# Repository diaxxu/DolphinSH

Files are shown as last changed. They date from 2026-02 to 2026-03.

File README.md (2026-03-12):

# VTOL FPV Fixed-Wing UAV Project

<p align="center">
 
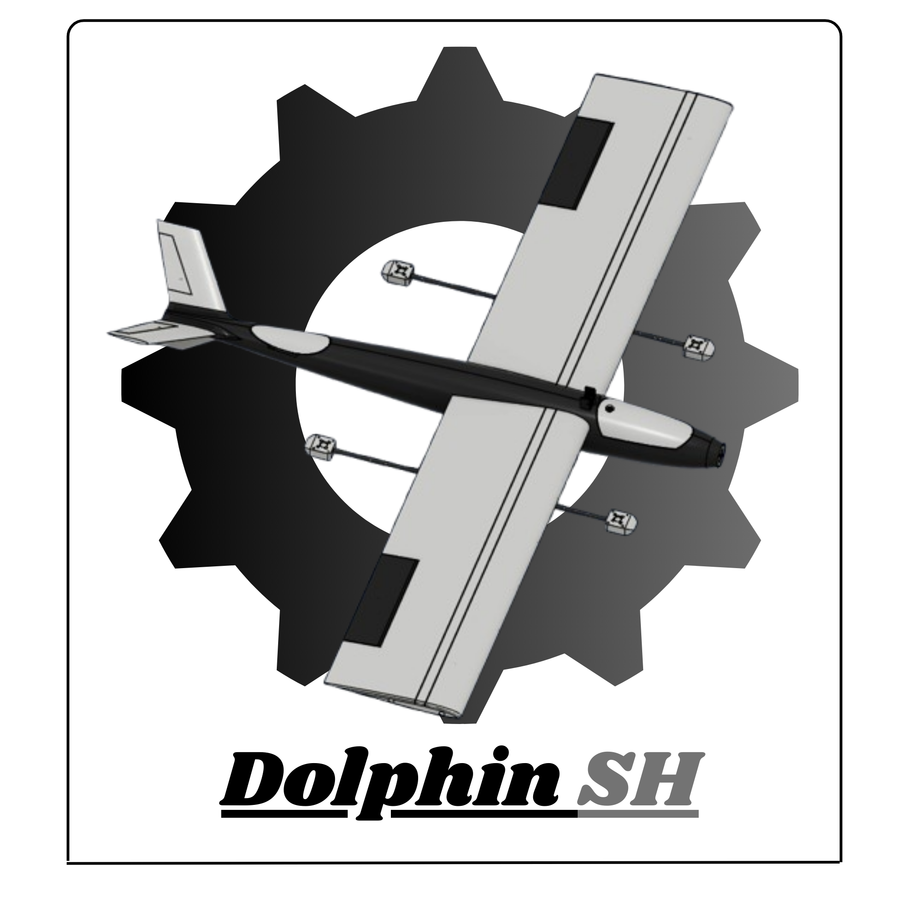
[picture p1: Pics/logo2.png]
Plane Front
   
</p>

### discord server : https://discord.gg/rtFu4ADm9m

## Overview

This project is a 3d printed VTOL (Vertical Take-Off and Landing) fixed-wing UAV with FPV (First Person View)  
It combines quad lift motors for vertical flight ( kinda like a drone ) but with a additional forward propulsion motor for efficient cruise.
I built this project to learn how to properly design, build a UAV (Unmanned Aerial Aircraft)

---

## Plane Features

- High-wing configuration
- 3d printed fuselage and wings (97% of the plane is 3d printed)  
- Quad vertical lift motors for VTOL capability  
- Nose-mounted motor for cruise propulsion  
- V tail configuration  
- Back fin designed for stability in forward flight at moderate speed
- easy access for mounting servo in the fuselage thanks to a BWD CAN and a FWD canopy

---

## Design Objectives
i made it to be or have : 
- Stable hover and smooth transition to forward flight  
- High structural stiffness with minimal weight  
- Efficient cruise performance  
- Predictable aerodynamic behavior at low Reynolds numbers  
- Modular fuselage for maintenance and upgrades  

---

## Technical Specifications 

- Wingspan: 1300 mm

- Wing Area: 0.286 m²

- Aspect Ratio: 5.9

- Wing Loading: 7.0 kg/m² (≈ 68.5 N/m²)

- Estimated Stall Speed: ~35 km/h (≈ 9.7 m/s)

- Cruise Speed (est.): ~72 km/h (20 m/s)

- Cruise Lift Coefficient (CL @ 20 m/s): ~0.28

- Reynolds Number (@ cruise): ~300,000

- Airfoil: Semi-Symmetrical (Cambered SS)

- Estimated Weight: 2046 g (~20 N)

- Fuselage Length: 888 mm

- Max Fuselage Diameter: 273 mm

## Propulsion

- Lift Motors: 4 × A2212 1000KV

- Max Thrust (VTOL total): ~3.2 kg

- VTOL Thrust-to-Weight Ratio: ~1.6

- Hover Endurance (est.): 4-6 minutes

- Cruise Motor: 1 × A2212 1000KV

- Cruise Power Consumption (est.): ~100 W

- Estimated Cruise Endurance: ~14–15 minutes

## Power System

- Battery: 3S 2200mAh 30C (~24 Wh usable energy)

- ESC: 30A (all motors)

## Avionics

- Flight Controller: DakeFPV F722 X6 (any F7 class FC compatible)
- GPS : HGRLC M-100
- ESC : generic 30amp
- FPV : generic one off aliexpress

---

## Firmware

the Firmware thats going to run is Inav its a lightweight program that is capable of autonomously flying the UAV to pre-programmed waypoint or loiter ( always wanted to do this imagine letting go of the transmitter and the plane continue to fly itself thats literally magic ) 

---

## Firmware Flashing Instructions

### 1. Install Required Software
1. Download and install **INAV Configurator** from the official GitHub release page.
2. Install the appropriate USB drivers for your flight controller (CP210x, STM32 VCP, or DFU drivers depending on the board).

### 2. Connect the Flight Controller
3. Connect the flight controller (FC) to your PC using a USB-C cable.
4. Wait for the operating system to recognize the device.
5. Confirm that a new COM port appears in your device manager.

### 3. Enter Bootloader Mode
6. If required, hold the **BOOT** button on the FC while plugging in the USB cable.
7. Alternatively, use the “Reboot to Bootloader” option inside INAV Configurator (if firmware is already present).

### 4. Flash Firmware
8. Open **INAV Configurator**.
9. Go to the **Firmware Flasher** tab.
10. Select the correct target for your flight controller (verify the exact board name printed on the FC).
11. Select the desired firmware version (use the latest stable release unless specific testing is required).
12. Enable **Full chip erase** (recommended for clean installations).
13. Click **Load Firmware Online**.
14. Click **Flash Firmware**.
15. Wait until flashing is complete. Do not disconnect power during this process.

### 5. Initial Setup
16. After flashing, reconnect to the FC.
17. Apply default settings.
18. Configure board alignment if necessary.
19. Calibrate the accelerometer.
20. Set up ports (UART configuration for receiver, GPS, etc.).
21. Configure receiver protocol.
22. Configure motor outputs and mixer type (VTOL / fixed wing as required).
23. Set failsafe parameters.
24. Save and reboot.

### 6. Verification
25. Confirm sensor functionality (gyro, accelerometer, barometer, GPS if installed).
26. Verify receiver inputs respond correctly.
27. Check motor output order and direction (remove propellers before testing).
28. Perform a final configuration backup.

attention! Firmware flashing and configuration must always be done without propellers installed to prevent accidental motor startup.

---

## Schematic ( wire diagram 
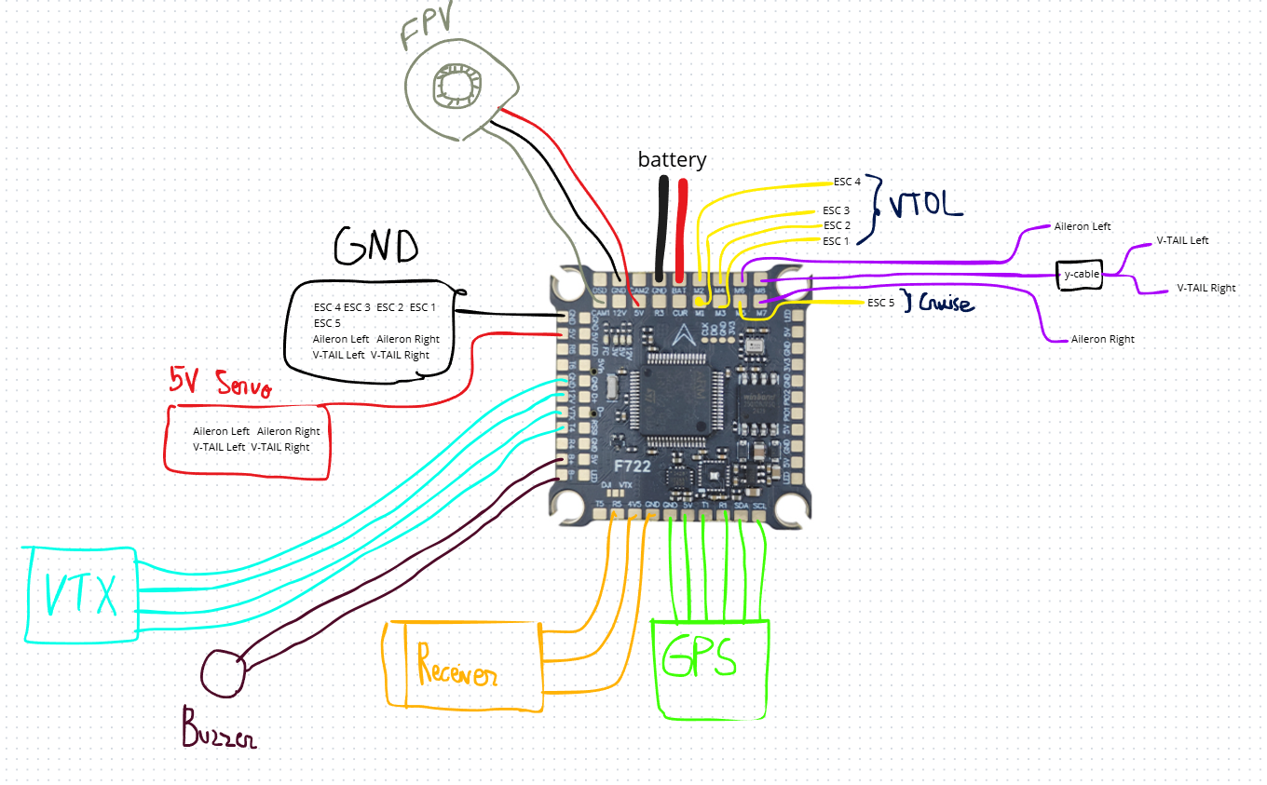
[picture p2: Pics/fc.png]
fc

-
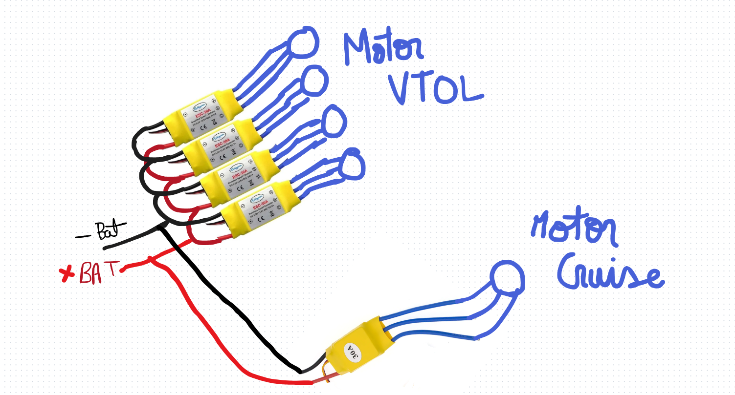
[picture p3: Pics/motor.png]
motor

-
---
## FAQ

**Q: Can this plane really hover like a drone?**  
A: Yes, the quad lift motors provide vertical takeoff and stable hover.

**Q: How difficult is the hover-to-cruise transition?**  
A: It’s one of the trickiest parts. Proper PID tuning in iNav and smooth throttle control are key to avoiding instability.

**Q: Can I use a different flight controller?**  
A: Yes, any controller that supports VTOL and iNav or Ardupilot firmware should work (and have 8 signal pins), though wiring and mounting may need adjustments. 

**Q: How long does it take to assemble?**  
A: Printing and assembly can take several days (or weeks!), depending on your 3D printing setup and experience. 

**Q: Is it possible to carry a camera payload?**  
A: Small FPV cameras work fine. =)

**Q: Can I scale the design larger or smaller?**  
A: Yes, but aerodynamics and weight distribution change with scale. Lift motors may need different thrust ratings.

**Q: How do you troubleshoot vibrations from the motor arms?**  
A: good carbon fiber tube is enough check for any error in the manufacturing side

**Q: How safe is the plane for beginners?**  
A: It’s moderately advanced. Beginners should test hover flights in a wide, open area and start with short, low-altitude hops.

**Q: What kind of maintenance is required?**  
A: Regularly check motor screws, propeller condition, and servo linkages. easy access panels in the fuselage makes replacing parts faster.

**Q: Can the firmware do autonomous flight?**  
A: Yes, iNav can handle waypoint navigation and loitering, letting the plane fly itself once configured correctly.

---

## COOL Pics

Plane VIS
-
PALEN
-
PALEN
-
PALEN

-
PALEN
-
Render
Plane Front
---

## Engineering Challenges

- Drag from exposed lift motors during cruise  
- Structural vibration and resonance of motor arms  ( simulation ) 
- Stable hover-to-cruise transition ( hard ) 
- Accurate CG placement ( moderate ) 

---

## BoM ( secret sauce!!) 
 
| Component | Specification | Quantity | Price  | Link |
| --- | --- | --- | --- | --- |
| Set of motor, ESC, and propellers | A2212 1000KV / 30A ESC / 23cm props | 4 | $64.01 | [AliExpress](https://a.aliexpress.com/_EJaQqYY) |
| FPV | Camera with VTX and goggle | 1 | $86.94 | [AliExpress](https://a.aliexpress.com/_EuSo3te) |
| Telemetry | LoRa LR02 ASR6601 (10 km range) | 1 | $25.63 | [AliExpress](https://a.aliexpress.com/_EJNQwhK) |
| Servo | SG90 (360°) | 5 | $8.78  | [AliExpress](https://a.aliexpress.com/_EHJRpG8) |
| Carbon Fiber Tube | 9x7x500 mm | 4 | $14.55 | [AliExpress](https://a.aliexpress.com/_EH2rwjI) |
| Servo Rods | 19 cm, 1.2 mm | 20 | $4.85  | [AliExpress](https://a.aliexpress.com/_EJKOflA) |
| Copper Wire (signal & FC) | 10 m, 26 AWG, yellow | 1 | $3.97  | [AliExpress](https://a.aliexpress.com/_EzUnszi) |
| Copper Wire (batteries) | 10 m, 16 AWG, black | 1 | $13.83 | [AliExpress](https://a.aliexpress.com/_EztPdHO) |
| Magnet | 3mmx1mm | 50 | $6.94  | [AliExpress](https://a.aliexpress.com/_EJExample)  |
| Square tube carbon fiber | 10x10x8.5mm 500mm | 2 | $16.7  | [AliExpress](https://a.aliexpress.com/_EJExample2) |
| Dupont line (connectors) | 10cm 3 kind | 120 | $5.07  | [AliExpress](https://a.aliexpress.com/_EJExample3) |
|Printing legion | shipping from india to morocco | 1 | $25 |  

i already own 1 flightcontroller , 1 motor , 1 esc , 1 battery, 1 gps , 1 receiver and transmitter 

### the TOTAL : 291.11$

## Credits

A big thanks to Hack Club and Blueprint for making this possible without them, all these project would been just a .step file <p/> 
also i want to thank the Reviewers who are doing an incredible job, kudos !

---
## Disclaimer
<p align="center">
 Plane Front
</p>
This project is experimental and intended for research and educational purposes.  
All flight testing must be conducted in safe and controlled environments.

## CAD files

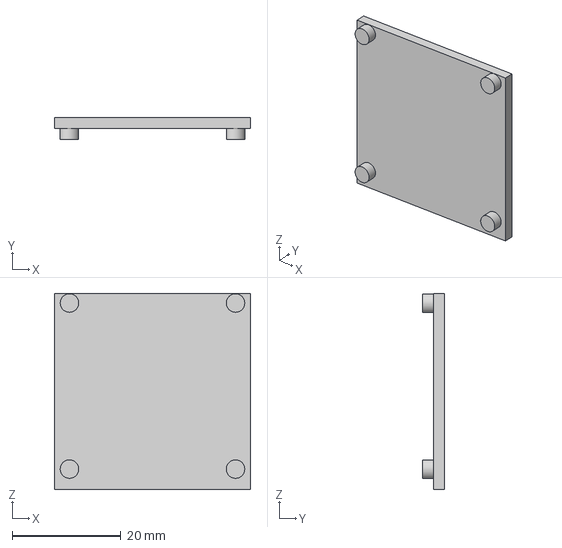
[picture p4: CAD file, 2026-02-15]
CAD/flight controller.step
36.0 x 4.00 x 36.0 mm

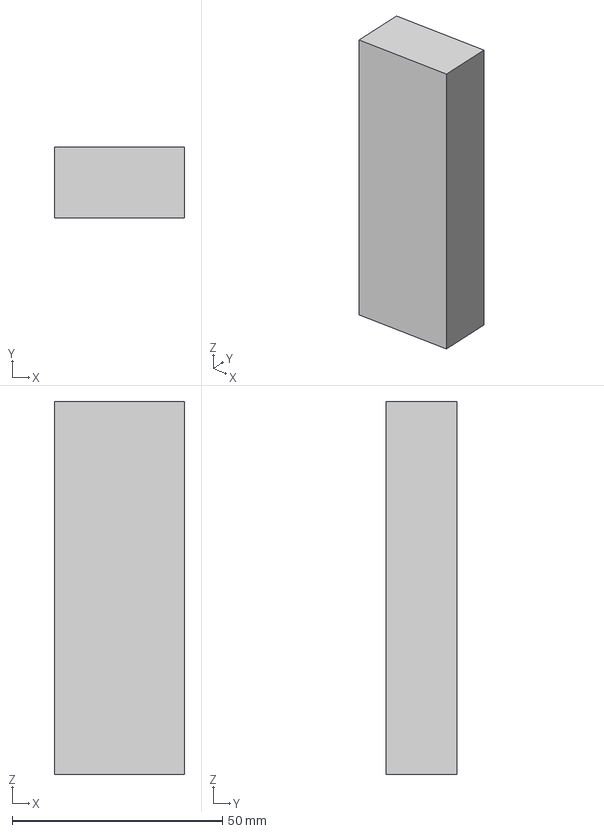
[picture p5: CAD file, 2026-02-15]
CAD/battery.step
31.0 x 17.0 x 88.7 mm

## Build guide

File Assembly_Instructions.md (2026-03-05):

# VTOL Aircraft Assembly Instructions

## 1. Wing Assembly
1. Assemble the wing structure according to the wing layout drawing.
2. Insert and secure the carbon fiber reinforcement rods inside the wing.
3. Install the wing servo in its designated servo bay.
4. Secure the servo and connect the control linkage to the control surface.
5. Verify smooth movement and ensure there is no binding.

## 2. Fuselage Assembly
6. Assemble the fuselage structure.
7. Install the rear fuselage servo in its mounting location.
8. Secure the servo and connect the linkage.
9. Verify full and smooth control surface deflection.
10. Mount the flight controller inside the fuselage using M3 screws.
11. Use vibration isolation if required.

## 3. Structural Integration
12. Slide the wing into the fuselage and secure it according to the design.
13. Insert the carbon fiber square tubes (booms) through the wing structure.
14. Ensure correct alignment and equal extension on both sides.
15. Install the four motor pods, one at each end of the booms.
16. Secure the motor pods firmly.

## 4. Motor Installation
17. Mount the four VTOL motors into the motor pods.
18. Install the cruise motor in the nose.
19. Tighten all mounting screws and apply threadlocker where appropriate.

## 5. Wiring and Electronics
20. Route all motor and servo wires through their designated channels and openings.
21. Extend motor and servo wires as required.
22. Solder all connections to the flight controller according to the official wiring diagram.
23. If using a different flight controller, refer to its specific pinout documentation.
24. Install the FPV camera in the nose and secure it.
25. Install all remaining avionics inside the fuselage (ESCs, GPS, receiver, power distribution, etc.).
26. Secure all components to prevent vibration or movement.

## 6. Final Checks
27. Verify the center of gravity (CG).
28. The CG must be located at 25% of the wing chord measured from the leading edge.
29. Perform control surface direction checks.
30. Verify motor rotation direction.
31. Confirm firmware configuration and failsafe operation before flight.

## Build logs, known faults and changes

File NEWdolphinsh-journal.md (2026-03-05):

<!--
  This journal is auto generated by Hack Club Blueprint.
-->

# 2/11/2026 - starting with CAD  

_Time spent: 12.0h_  

## CAD
i started with the rough shape then went into detail i designed the internal structure of the wing, the fuselage and winglets. i then made the elevon ( mix of aileron and elevator ) 

---

# tomorrow goals 
- ill make designated servo spots on the wings
- add motor and design motor mount 
well thats it for today see you !

## pics

 
Capture d'écran 2026-02-11 204641



# 2/12/2026 - update  

_Time spent: 9.0h_  

the old aircraft shape is too complex for me im going to change it for something easier to fly and cheaper to print since then i arrived to this design ( btw did i say its going to be vtol!) 
## what i did 
- i designed the fuselage
- the wing and its internal structure 
- vtol motor support 
- aileron mechanism

---

## tomorrow objectif

- design the empenage (tail section)
- shell the fuselage 
- work on the interior fuselage 
- choose if its going to be a tractor config or a pusher 

# PICS

Capture d'écran 2026-02-12 161114

# 2/13/2026 12 PM - 80% CAD finished  

_Time spent: 9.0h_  

# here is what i did 

- tail section is now finished 
- added servo well and horn in ailerons and in the v tail 
- added two canopy for easy component access 
- a fpv slot where u screw in a fpv camera ( with +-5deg) 
- also extruded servo wire hole in the wing to pass them thru the wing 
- added an air vent to cool the inside also pass the motor wire thru them 

---

# to-do

- add esc wire holes in the wing 
- internal structure for placing ( flight controller / battery / esc )
- gps placement 
- model each electric component in place 

---

# pics

Capture d'écran 2026-02-13 001933Capture d'écran 2026-02-12 222748Capture d'écran 2026-02-13 001837Capture d'écran 2026-02-13 001849Capture d'écran 2026-02-13 001858


thanks for ur time   

# 2/13/2026 11 PM - finishing touches   

_Time spent: 4.0h_  

added the flight controller and battery structure 


cut the esc holes in the wings both placement and wire 


hole where the all the external wire go into the fuselage straight into the flight controller and battery 


esc hiding spot :8


found gps (gnss) place yay :-)


optimized weight and sleekness hehe


# to do

- set up a github for this project 
- make a Bom ( bill of Material ) 
- optimize design and find errors 

# 2/15/2026 4 PM - github  

_Time spent: 7.0h_  

finished setting up the repo : 
- made a beautiful readme.md
- added a BOM.csv
- custom logo
- gave the project a name yay!
- cool render and images
added the cad folder where the full assembly is and electronics 
added the firmware that i am going to use (inav) 
finally making sure that my repo look beautiful ")
i will try to run some simulation to see how much lift does it product and let you guys see those beautiful colors 

# 2/15/2026 11 PM - Simulation  

_Time spent: 6.0h_  

well i simulated my aircraft in SimScale and here is the results: 
Capture d'écran 2026-02-15 220745
everything is looking good the leading edges are red since they are head-on Capture d'écran 2026-02-15 220543Capture d'écran 2026-02-15 221323Capture d'écran 2026-02-15 220739Capture d'écran 2026-02-15 221256
i got 0.53 lift coefficient Cl thats impressive knowing the airfoil
Capture d'écran 2026-02-15 222314
drag of the motor support and the Carbon Fiber Tube
Capture d'écran 2026-02-15 222306Capture d'écran 2026-02-15 221520
sleek fuselage with minimal drag
Capture d'écran 2026-02-15 221323Capture d'écran 2026-02-15 220558
btw I'm still new to simulation and actively learning.

# 2/16/2026 5 PM - prepared the fuselage for 3d printing   

_Time spent: 4.0h_  

i cut the fuselage to fit the 3d printer i will add later connector to make assembly later easy also here is the specs i got from bambulab with 0% infill and 3 walls Capture d'écran 2026-02-16 175339
Capture d'écran 2026-02-16 175543

614g is okay since we are using pla and not LW-pla i believe we can make the aircraft lighter than the estimated weight by 200 to 600g

# 2/16/2026 10 PM - Assembly instruction   

_Time spent: 4.3h_  

i made the assembly instruction for my 3d printed uav its very easy as simple as playing with lego, i believe that anyone can make this plane on his own anyways wiring/electrical instruction is coming soon also a discord server for this specific plane is going to be created !! 

## stay tuned ಥ_ಥ











# 2/17/2026 - discord server   

_Time spent: 5.0h_  

i just made a discord server for this specific plane where people can request help assembling their Dolphin rc plane and also chill and socialize since i know little about making discord server it took me a while to set it up, here is the link for the interested : https://discord.gg/rtFu4ADm9m 

# 2/18/2026 - more optimization   

_Time spent: 5.0h_  

i made the fuselage more aerodynamic this come with augmented flight time and efficient flight furthermore i added a usb-c port hole in the nose section for easy plug 

# after doing some static testing i made the carbon fiber tube support studier to hopefully remove vibration 

# Sketched the esc placement for the best cooling configuration



fillet on the vertical stab 

# 2/26/2026 - other alternatives ?   

_Time spent: 2.0h_  

After someone suggested I use PCBWay’s printing service, I uploaded all the files and checked the total cost. It turned out to be way more expensive than I expected and that’s without even including shipping. So at this point, I don’t really have a choice but to look for a local 3D printing service since it’s much more affordable (-:



# 2/27/2026 - Revision  

_Time spent: 4.0h_  

More in-depth calculation and some more optimization like the fpv fairing to reduce drag and maximize efficiency Also the new calculation is now available on the github repo go check it out ! 
furthermore after i posted my aircraft in a specialized 3d printing plane reddit i had so much valuable feedback. They suggested that I need to increase the size of the V-tail to maintain adequate tail authority I also reduced the size of the vertical fin to prevent it from interfering with the flight controller during VTOL descents and to avoid the hopping issue. 

 



here is the up to date version of the Dolphin-SH  

# 3/4/2026 - added wire diagram in github  

_Time spent: 2.0h_  

i made this diagram for the flightcontroller and its avionics ( gps , fpv camera , vtx , buzzer , receiver and servos ) i tried really hard to make it easy for people who want to recreate this wonderful plane ! (●'◡'●)
motor
fc

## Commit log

2026-02-15 Enhance README with FAQ and updates
    Added a FAQ section to address common questions about the plane's capabilities, assembly, maintenance, and safety for beginners. Updated credits and disclaimer sections for clarity.
2026-02-27 Revise technical specifications and add propulsion details
    Updated technical specifications, propulsion, power system, and avionics sections in README.md.
2026-03-05 Add VTOL Aircraft Assembly Instructions
    Added detailed assembly instructions for VTOL aircraft, covering wing, fuselage, structural integration, motor installation, wiring, and final checks.
2026-03-12 Revise BoM with updated components and pricing
    Updated the Bill of Materials (BoM) with new specifications, quantities, and prices for various components. Adjusted the total cost to reflect the new items.
